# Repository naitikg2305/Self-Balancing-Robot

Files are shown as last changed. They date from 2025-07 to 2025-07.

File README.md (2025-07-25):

# Self-Balancing Robot

Welcome to the official project page for our Self-Balancing Robot. This website showcases the development, implementation, and final results of our autonomous two-wheeled balancing robot. Built as part of our control systems course (ENEE/ENME 461), this project merges hardware, software, and control theory into a compact, responsive platform.

---

## 🚀 Introduction

Inspired by the classic inverted pendulum problem, our robot demonstrates real-time balance using sensor feedback and PID control. It uses an ESP32 microcontroller, an MPU6050 IMU, and two DC gear motors controlled via a dual H-bridge. The challenge? Keep the robot upright on just two wheels—like a miniature Segway.

---

## 🛠️ Hardware Design

Our robot features:

- **Microcontroller:** ESP32 (DevKit v1)
- **Sensor:** MPU6050 (6-DOF IMU)
- **Motors:** 2x Pololu 3701 6V DC gear motors
- **Motor Driver:** L298N Dual H-Bridge
- **Power:** 12V Li-ion battery, 2x buck converters for 5V/3.3V
- **Frame:** 3D-printed chassis, with electronics mounted low for stability
- **Extras:** Darth Vader figurine on top for aesthetics!

> **Wiring Note:** We routed power from the 12V battery through buck converters to deliver clean 5V and 3.3V for logic and sensor components. All grounds from the Arduino, H-bridge, IMU, and buck converters are tied together to form a common ground reference. Motor power lines run directly from the battery to the L298N to handle current draw, while logic control pins are connected from the Arduino to the H-bridge via digital pins. I²C lines from the MPU6050 are connected to A4 and A5, with pull-up resistors handled internally. Each connection was tested using a multimeter for continuity, and critical joints were soldered and insulated with shrink wrap for durability.

All components were selected based on torque calculations and center of mass optimization. The wheels are 5 inches in diameter, offering a balance between responsiveness and ground clearance.

> The IMU is mounted close to the motors to reduce sensor lag and noise, while the battery is positioned low in the chassis to help with overall center of mass and balancing. The buck converters provide stable 5V and 3.3V rails from the main 12V battery, which also directly powers the motors and is safe for the Arduino’s VIN input (which tolerates up to 12V). Even with a 2V drop across the motors, our logic power is regulated and isolated from load variations.

### 🧵 Wiring Details

We routed power from the 12V battery through buck converters to deliver clean 5V and 3.3V for logic and sensor components. All grounds from the Arduino, H-bridge, IMU, and buck converters are tied together to form a common ground reference. Motor power lines run directly from the battery to the L298N to handle current draw, while logic control pins are connected from the Arduino to the H-bridge via digital pins. I²C lines from the MPU6050 are connected to A4 and A5, with pull-up resistors handled internally. Each connection was tested using a multimeter for continuity, and critical joints were soldered and insulated with shrink wrap for durability.

---

---

## 📐 CAD and Mechanical Assembly

The chassis was designed using Fusion360 and printed with PLA. The base houses the motors, driver, and battery. A custom bracket mounts the IMU at wheel axle level to reduce measurement noise. Zip ties and shrink tubing were used to secure and organize wires.

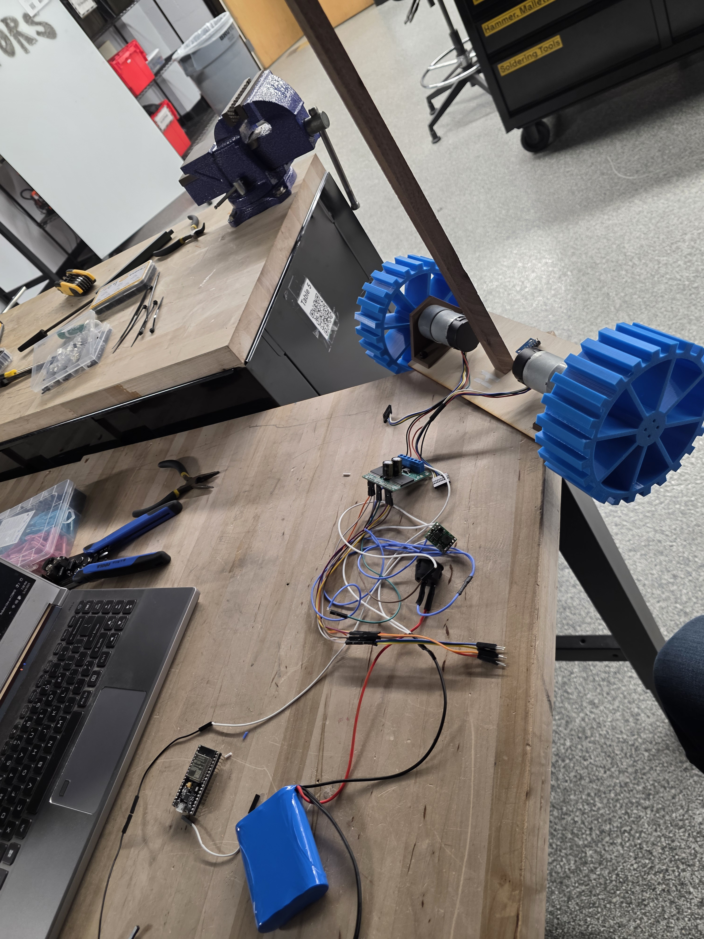
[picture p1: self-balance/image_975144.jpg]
 
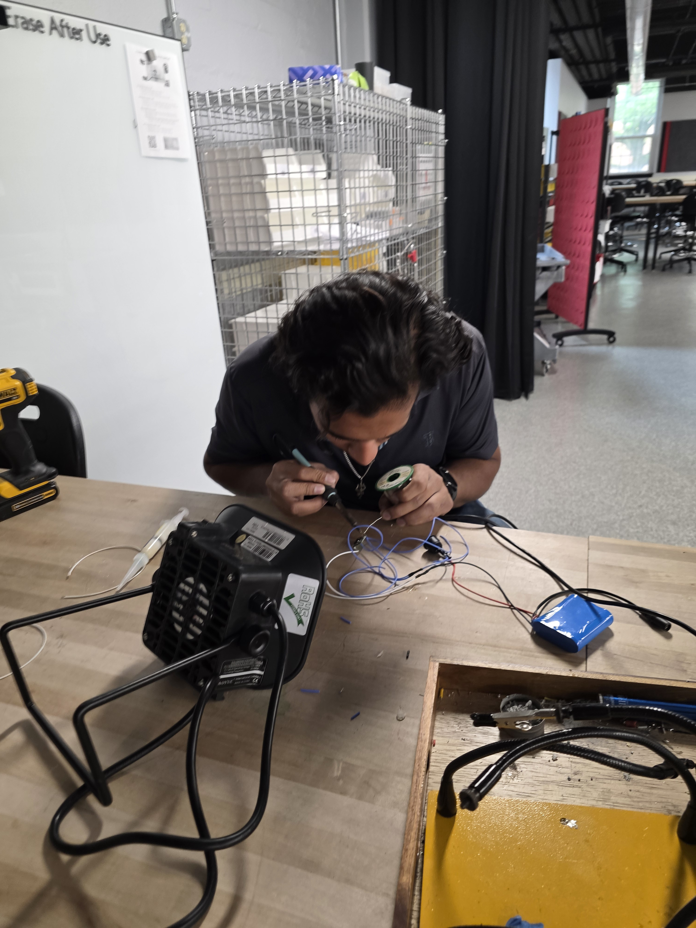
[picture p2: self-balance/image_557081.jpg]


---

## 🧠 Control System

We implemented a PD (Proportional-Derivative) control loop in C++ on the ESP32. Real-time pitch angle is read from the MPU6050, processed, and used to drive the motors with appropriate speed and direction. The system runs a loop every few milliseconds and includes a safety cutoff if the robot tilts beyond ±25°.

Key features:
- MPU6050 offset calibration at boot
- PWM-based motor control
- Dead zone for motor inputs below threshold
- Safety limits for excessive tilt

---

## 🧪 Testing and Tuning

Initial tuning was done using only the proportional term (Kp). We observed oscillations and instability at high Kp values. Adding the derivative term (Kd) improved stability and response time.

Final stable tuning:
- Kp: 3
- Kd: 300–450 (varies by configuration)

We used MS Excel’s Data Streamer to collect and visualize data from serial output, allowing analysis of angle, error, and motor input over time.

---

## 📹 Demo and Results

Our robot successfully balances under mild disturbances and showcases dynamic feedback in action. It reacts quickly, stabilizes after nudges, and remains upright unless excessive weight or tilt is applied.

---

## 🔧 Full Parts List

Refer to the shopping list document for exact components. Major items include:
- ESP32 DevKit
- MPU6050 IMU
- L298N Motor Driver
- 2x DC Gear Motors
- 12V Li-ion Battery
- 2x Buck Converters
- Custom 3D Printed Frame
- Darth Vader Figurine 😎
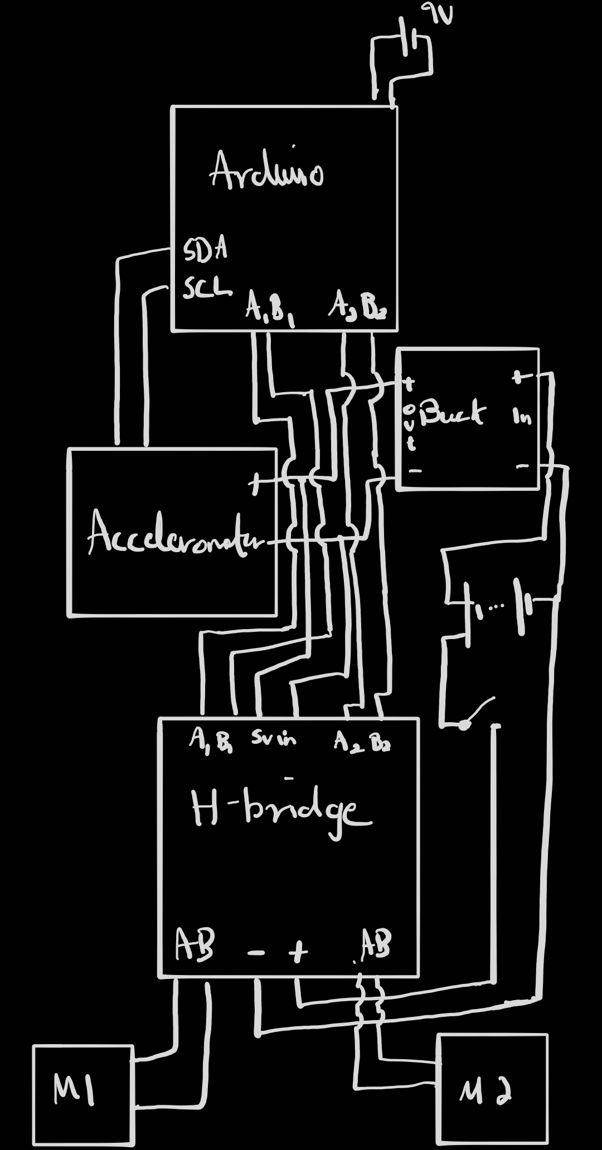
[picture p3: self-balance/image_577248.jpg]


---
## 🔌 Wiring Table

| Function | Component | Arduino Pin | Direction | Notes |
|---|---|---|---|---|
| Motor A DIR 1  | H-Bridge INA1 | D7 | Output | Sets forward/reverse |
| Motor A DIR 2  | H-Bridge INB1 | D8 | Output | |
| Motor A PWM | H-Bridge PWM1  | D5 | PWM Output | |
| Motor B DIR 1  | H-Bridge INA2 | D9 | Output | |
| Motor B DIR 2  | H-Bridge INB2 | D10 | Output | |
| Motor B PWM | H-Bridge PWM2  | D6 | PWM Output | |
| I²C SDA | MPU6050 | A4 | I²C | Connects to MPU6050 SDA |
| I²C SCL | MPU6050 | A5 | I²C | Connects to MPU6050 SCL |
| 5V Logic Power | H-Bridge / IMU  | - | Power | From 5V buck converter |
| GND | All Devices | - | Ground | Common ground for all |
| VIN | 9V Battery | VIN | Power Input | Powers Arduino Uno |

---

## 📅 Timeline

**Week 1:**
- Finalize CAD and ESP32 code
- Test IMU communication
- Set up buck converters

**Week 2:**
- Assemble robot frame
- Integrate electronics
- Start PID integration

**Week 3:**
- Tune PID controller
- Perform final testing
- Record demo and finalize documentation

---

## 🎓 Conclusion

This project was a successful application of control theory, hardware integration, and real-time feedback systems. Despite minor hardware limitations (motor torque, wheel grip), we achieved a reliable self-balancing robot that visually and functionally reflects our knowledge in embedded control.

---

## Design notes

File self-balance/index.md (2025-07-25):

---
title: "Self-balancing Robot using PID control"
date: "2025-05-20"
tags: ["PID Control", "IOT"]
summary: "This website showcases the development, implementation, and final results of our autonomous two-wheeled balancing robot."
youtube: "https://youtube.com/..."
featured: true   # only include if it's a featured project

stls: ["./wheel.stl"]
excels: ["./data/PD_kp3_kd0.25.csv","./data/PDkp3kd250.csv","./data/PDkp3kd650_final.csv"]
docs: ["./proposal.docx", "./report.docx","./shopping.docx"]
---

# Self-Balancing Robot

Welcome to the official project page for our Self-Balancing Robot. This website showcases the development, implementation, and final results of our autonomous two-wheeled balancing robot. Built as part of our control systems course (ENEE/ENME 461), this project merges hardware, software, and control theory into a compact, responsive platform.

---

## 🚀 Introduction

Inspired by the classic inverted pendulum problem, our robot demonstrates real-time balance using sensor feedback and PID control. It uses an ESP32 microcontroller, an MPU6050 IMU, and two DC gear motors controlled via a dual H-bridge. The challenge? Keep the robot upright on just two wheels—like a miniature Segway.

---

## 🛠️ Hardware Design

Our robot features:

- **Microcontroller:** ESP32 (DevKit v1)
- **Sensor:** MPU6050 (6-DOF IMU)
- **Motors:** 2x Pololu 3701 6V DC gear motors
- **Motor Driver:** L298N Dual H-Bridge
- **Power:** 12V Li-ion battery, 2x buck converters for 5V/3.3V
- **Frame:** 3D-printed chassis, with electronics mounted low for stability
- **Extras:** Darth Vader figurine on top for aesthetics!

> **Wiring Note:** We routed power from the 12V battery through buck converters to deliver clean 5V and 3.3V for logic and sensor components. All grounds from the Arduino, H-bridge, IMU, and buck converters are tied together to form a common ground reference. Motor power lines run directly from the battery to the L298N to handle current draw, while logic control pins are connected from the Arduino to the H-bridge via digital pins. I²C lines from the MPU6050 are connected to A4 and A5, with pull-up resistors handled internally. Each connection was tested using a multimeter for continuity, and critical joints were soldered and insulated with shrink wrap for durability.

All components were selected based on torque calculations and center of mass optimization. The wheels are 5 inches in diameter, offering a balance between responsiveness and ground clearance.

> The IMU is mounted close to the motors to reduce sensor lag and noise, while the battery is positioned low in the chassis to help with overall center of mass and balancing. The buck converters provide stable 5V and 3.3V rails from the main 12V battery, which also directly powers the motors and is safe for the Arduino’s VIN input (which tolerates up to 12V). Even with a 2V drop across the motors, our logic power is regulated and isolated from load variations.

### 🧵 Wiring Details

We routed power from the 12V battery through buck converters to deliver clean 5V and 3.3V for logic and sensor components. All grounds from the Arduino, H-bridge, IMU, and buck converters are tied together to form a common ground reference. Motor power lines run directly from the battery to the L298N to handle current draw, while logic control pins are connected from the Arduino to the H-bridge via digital pins. I²C lines from the MPU6050 are connected to A4 and A5, with pull-up resistors handled internally. Each connection was tested using a multimeter for continuity, and critical joints were soldered and insulated with shrink wrap for durability.

---

---

## 📐 CAD and Mechanical Assembly

The chassis was designed using Fusion360 and printed with PLA. The base houses the motors, driver, and battery. A custom bracket mounts the IMU at wheel axle level to reduce measurement noise. Zip ties and shrink tubing were used to secure and organize wires.

 


---

## 🧠 Control System

We implemented a PD (Proportional-Derivative) control loop in C++ on the ESP32. Real-time pitch angle is read from the MPU6050, processed, and used to drive the motors with appropriate speed and direction. The system runs a loop every few milliseconds and includes a safety cutoff if the robot tilts beyond ±25°.

Key features:
- MPU6050 offset calibration at boot
- PWM-based motor control
- Dead zone for motor inputs below threshold
- Safety limits for excessive tilt

---

## 🧪 Testing and Tuning

Initial tuning was done using only the proportional term (Kp). We observed oscillations and instability at high Kp values. Adding the derivative term (Kd) improved stability and response time.

Final stable tuning:
- Kp: 3
- Kd: 300–450 (varies by configuration)

We used MS Excel’s Data Streamer to collect and visualize data from serial output, allowing analysis of angle, error, and motor input over time.

---

## 📹 Demo and Results

Our robot successfully balances under mild disturbances and showcases dynamic feedback in action. It reacts quickly, stabilizes after nudges, and remains upright unless excessive weight or tilt is applied.

---

## 🔧 Full Parts List

Refer to the shopping list document for exact components. Major items include:
- ESP32 DevKit
- MPU6050 IMU
- L298N Motor Driver
- 2x DC Gear Motors
- 12V Li-ion Battery
- 2x Buck Converters
- Custom 3D Printed Frame
- Darth Vader Figurine 😎


---
## 🔌 Wiring Table

| Function | Component | Arduino Pin | Direction | Notes |
|---|---|---|---|---|
| Motor A DIR 1  | H-Bridge INA1 | D7 | Output | Sets forward/reverse |
| Motor A DIR 2  | H-Bridge INB1 | D8 | Output | |
| Motor A PWM | H-Bridge PWM1  | D5 | PWM Output | |
| Motor B DIR 1  | H-Bridge INA2 | D9 | Output | |
| Motor B DIR 2  | H-Bridge INB2 | D10 | Output | |
| Motor B PWM | H-Bridge PWM2  | D6 | PWM Output | |
| I²C SDA | MPU6050 | A4 | I²C | Connects to MPU6050 SDA |
| I²C SCL | MPU6050 | A5 | I²C | Connects to MPU6050 SCL |
| 5V Logic Power | H-Bridge / IMU  | - | Power | From 5V buck converter |
| GND | All Devices | - | Ground | Common ground for all |
| VIN | 9V Battery | VIN | Power Input | Powers Arduino Uno |

---

## 📅 Timeline

**Week 1:**
- Finalize CAD and ESP32 code
- Test IMU communication
- Set up buck converters

**Week 2:**
- Assemble robot frame
- Integrate electronics
- Start PID integration

**Week 3:**
- Tune PID controller
- Perform final testing
- Record demo and finalize documentation

---

## 🎓 Conclusion

This project was a successful application of control theory, hardware integration, and real-time feedback systems. Despite minor hardware limitations (motor torque, wheel grip), we achieved a reliable self-balancing robot that visually and functionally reflects our knowledge in embedded control.

---

## 📁 Appendix

- [Final Report (PDF)](link-to-pdf)
- [Shopping List (PDF)](link-to-shopping-list)
- [Proposal and Technical Details](link-to-proposal)
- [Demo Videos](https://drive.google.com/drive/folders/1PLejTndw4LxtoSVA8v18seIj9uFeChZ4?usp=sharing)

---

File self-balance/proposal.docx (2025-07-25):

# Name: Naitik Gupta, Stephen Snyder

# Self-Balancing Robot Project Proposal

# Project Description and Justification

We are designing a self-balancing two-wheeled robot using an ESP32 microcontroller, an MPU6050 IMU, two 6V DC gear motors (Pololu 3701), and a dual H-bridge motor driver (L298N). The robot will maintain balance using PID control, with real-time feedback from the IMU mounted near the wheel axle to sense pitch angle and angular velocity. All control logic and sensor processing will be executed on the ESP32, powered through a buck converter. A second buck converter powers the motor driver logic separately.

The robot is powered by a 12V Li-ion battery pack, chosen to provide sufficient headroom for torque delivery. The L298N introduces a voltage drop of approximately 2V, meaning motors effectively receive ~10V. At this voltage, the selected gear motors can deliver up to 2.0 kg·cm stall torque. Our torque calculations indicate that to correct a forward tip of 5 degrees with our estimated 1 kg robot (0.6 kg electronics below axle, 0.2 kg figurine above axle), approximately 0.024 Nm (2.45 kg·cm) of total torque is required. With two motors, each motor needs to provide around 1.2 kg·cm of torque, which is well within the motors’ performance range when overdriven safely at 10V. The use of 5-inch wheels ensures good ground contact and stability, while the low placement of the battery and electronics counterbalances the raised decorative figurine.

At its core, this project aims to explore the challenge and elegance of balancing a robot on just two wheels — a feat that captures the essence of modern control systems. Achieving upright stability using only sensor feedback and dynamic motor control illustrates how theory translates into practical, physical behavior. It's an exciting demonstration of how real-time physics, electronics, and programming converge into a functioning, responsive system.

This project is worthwhile as it combines essential control systems concepts such as feedback, PID tuning, real-time actuation, and dynamic stabilization. It gives us hands-on experience with nonlinear system control, sensor fusion, and system modeling—key competencies in control engineering.

# Feasibility and Planning

We have studied self-balancing robot implementations and PID control techniques using MPU6050 and ESP32 platforms. We are implementing complementary filtering or Kalman filtering to obtain a stable pitch estimate. Motor speed and direction will be controlled via PWM signals generated by the ESP32 and routed through the L298N. All hardware components have been selected to match our physical requirements and torque targets. We understand the limitations of the L298N and have compensated by using a 12V battery with dedicated buck converters to provide stable 5V and 3.3V outputs for the ESP32 and driver logic respectively.

# Timeline and Milestones

- 📆 Week 1 (Apr 21 – Apr 27): Finalize software structure, write low-level drivers for ESP32, and implement IMU communication and filtering. Finalize CAD design for robot chassis and mounts. Test buck converters and individual hardware modules.
- 📆 Week 2 (Apr 28 – May 4): Assemble mechanical frame and install all electronic components. Test full power distribution and PWM-based motor control. Begin integrating IMU data into balance logic.
- 📆 Week 3 (May 5 – May 11): Tune PID controller and verify balance behavior. Perform rigorous testing with weight distribution and evaluate robustness. Finalize report, demonstration, and documentation.

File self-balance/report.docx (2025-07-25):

ENME/ENEE 461

Controls Project - Self-Stabilizing Robot

Stephen Snyder, Naitik Gupta

Introduction

Goal

Our main goal for this project is to apply our knowledge and learnings from this semester into a real world application that presents our mastery of the course. For this, we chose to design a self-balancing robot, similar in design to a Segway. We got our inspiration from the inverted pendulum project where we had to design a PD controller that kept a metal pendulum upright using a metal arm that spins. In our case, we used two 12v motors that were fast and had enough torque to keep the robot from tipping over too much.

Hypothesis

Using a PD controller with an accelerometer that calculates the change in angle as input is a viable way to control two motors with varying speeds to keep a self-balancing robot upright.

Design

CAD Model

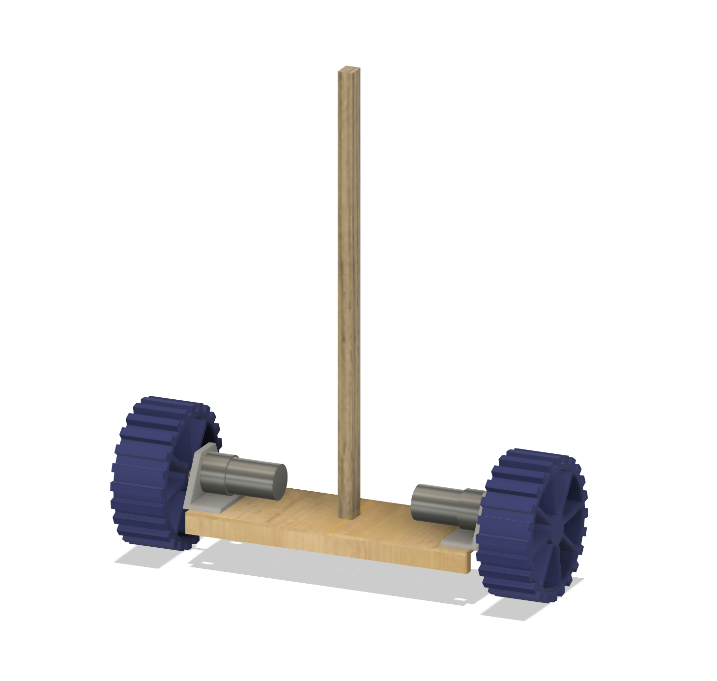
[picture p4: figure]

Fig 1: CAD model of the robot

Our robot was designed in Fusion360. It consists of two motors mounted to a baseplate, wheels on the ends, and a stick in the middle. During the fabrication process, extra support pieces were added to the underside of the base to keep it from bowing, which has been reflected in the CAD model.

Motor Justification

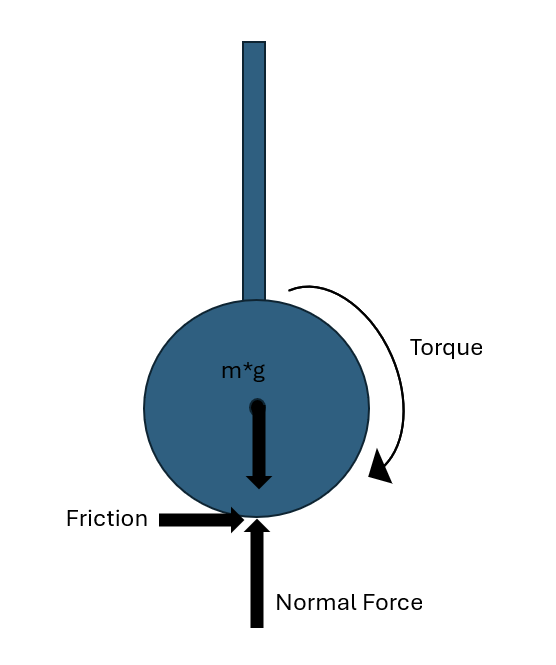
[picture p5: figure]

Fig 2: Free-body diagram of the robot

We derived the necessary torque per motor using a rough force balance of the vehicle and the motor torque, assuming a friction coefficient of ~0.3, a wheel radius of 130mm, and a weight of 1kg.

T =m*g*c_f *r*1/2

This worked out to be 0.191 N-m (1.95 kg-cm) of torque per motor in order to make our robot move.

Parts Used

We used two 12V DFRobot motors. They had a max speed of 251RPM and a stall torque of 18 kg-cm, which was enough for the motors to be able to spin even when the voltage applied was well under 12V.

Two motor mounting brackets designed by us were printed in PLA to connect the motors to the baseplate.

A Pololu MD03A Dual H-Bridge was use to control the power sent to the motors. An H-bridge allows us to control both the direction of the motors and the speed, which is necessary for our controller to function.

A 12V, 3000mAh rechargeable Li-ion battery was used as our power supply for the motors. This had the voltage and the current discharge rate necessary to power our motors, while also being lightweight. A kill switch was soldered into the power output wire to allow us to quickly shut down the robot.

A buck converter was used to step down the voltage from 12V to 5V to provide power to the accelerometer and H-bridge.

We intended to use an ESP32 as our microcontroller due to its 240MHz response speed which would provide enough speed to react to changing angle values. However, the ESP32 gave us a lot of problems. Specific drivers needed to be found for it to even interact with our computer(silicon labs cp210x USB to UART drivers). Then, the boot button needed to be held every time we tried to upload code. The COM port kept switching every time we tried to upload the code, as did the board drivers in arduino: we used ALKS 4D sometimes, 4d Systems drivers other times. Finally, once the code was able to be uploaded, the GPIO pins outputted negative voltage signals and could not switch H-bridge logic, so we decided not to use it.

We instead used an Arduino Uno, and even with a slower speed of 16MHz it was fast enough to effectively control the robot.

An Adafruit MPU6050 6-DOF accelerometer was used to get angle readings. It was mounted low to limit noise, as close to the axles of the motor around which the robot would primarily turn, and readings from only the X-direction were used.

Our wheels were 130mm in diameter and were printed in TPU to give it better grip. We wanted the wheels to be large to accommodate our circuits and battery without throwing the rover too off balance. 130mm enabled us to fit the battery at the bottom and the rest of the circuits over the axle which gave us just enough slight imbalance for our PID to work and self balance. We later wrapped the wheels in duct tape to give it even more grip.

A small PLA wheel hub with a set screw was used to connect the motor shaft to the wheels.

A piece of 1/8" (3.175mm) plywood was laser cut to 100x275mm as the baseplate.

A scrap piece of wood, roughly 14x18x420mm, was placed vertically in the center both to give a clear indicator of the current angle and to add enough weight above the robot to unbalance it.

Two pieces of scrap wood, roughly 8x17x275mm, were used to support the baseplate from bowing.

With the exception of the battery, which was mounted to the underside to keep it more secure, all parts were mounted on the baseplate. As much of the weight as possible was placed above the axis of rotation to cause the robot to be unstable while at rest.

Wiring diagram

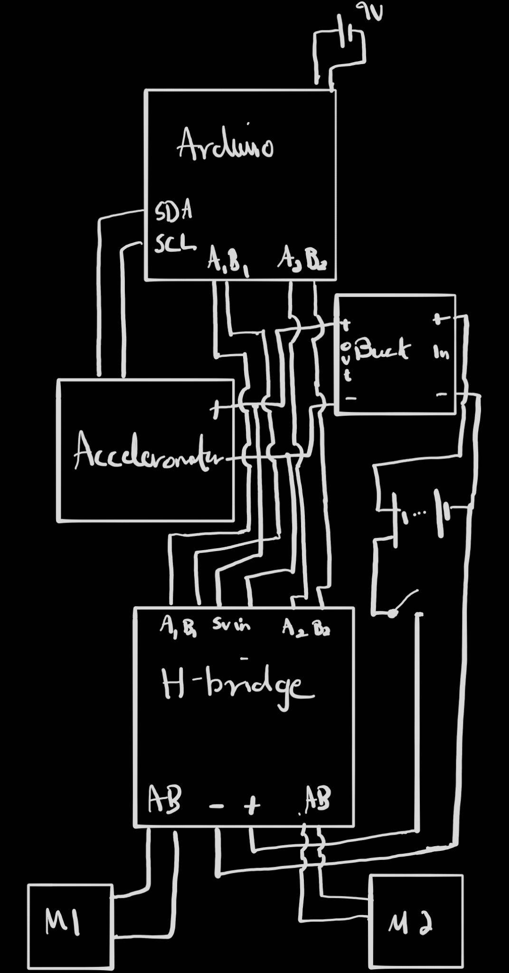
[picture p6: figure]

Fig 3: Wiring diagram

Pinout

Function | Component | Arduino Pin | Direction | Notes
Motor A DIR 1 | H-Bridge INA1 | 7 | Output | Sets forward/reverse
Motor A DIR 2 | H-Bridge INB1 | 8 | Output | Sets forward/reverse
Motor A PWM | H-Bridge PWM1 | 5 | PWM Output | Sets speed
Motor B DIR 1 | H-Bridge INA2 | 9 | Output | Sets forward/reverse
Motor B DIR 2 | H-Bridge INB2 | 10 | Output | Sets forward/reverse
Motor B PWM | H-Bridge PWM2 | 6 | PWM Output | Sets speed
I²C SDA | MPU6050 | A4 | I²C | Connects to MPU6050 SDA
I²C SCL | MPU6050 | A5 | I²C | Connects to MPU6050 SCL
5V Logic Power | H-Bridge / MPU6050 | - | Power | From 5V buck converter
GND | All Devices | - | Ground | Common ground for all
VIN (Arduino) | 9V Battery | VIN | Power Input | Powers Arduino Uno
Function | Component | Arduino Pin | Direction | Notes

Final Design

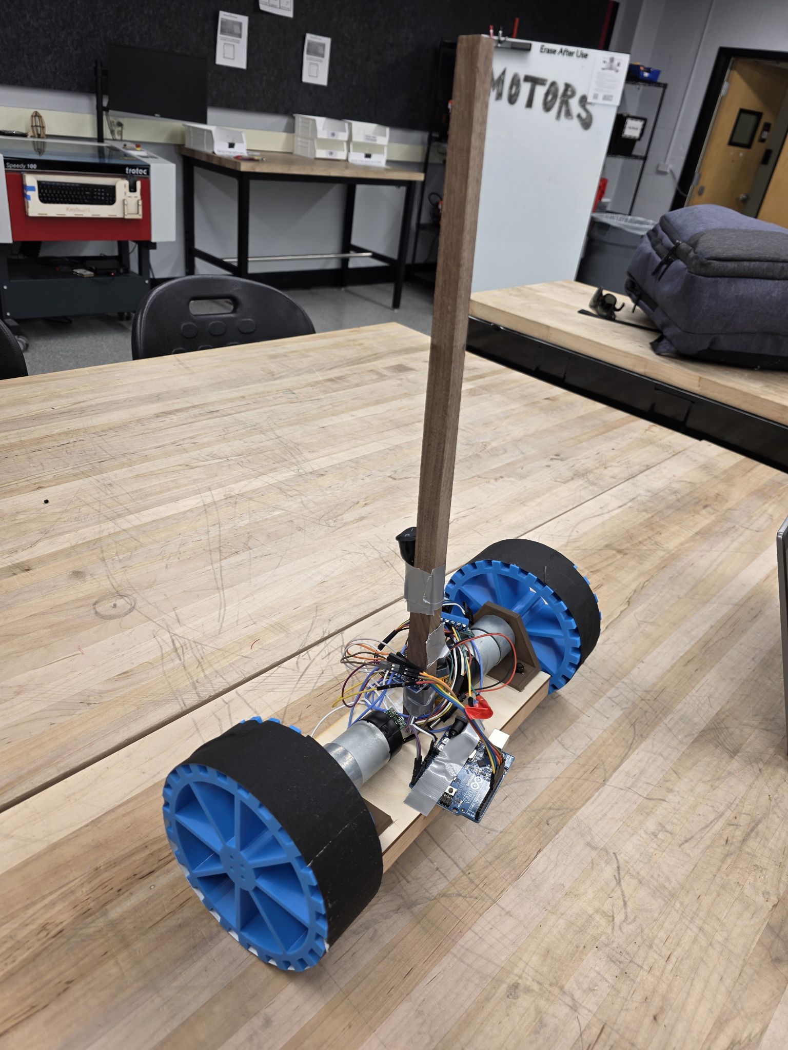
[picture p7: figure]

Fig 4: Fully built robot

Code

Initial Calibration Code

We first tested the output from the accelerometer using the code below, found as an example within the accelerometer library. This outputs the angle in the X direction, the acceleration in the Y direction, and the gyroscopic force in the Z direction. The angle value was the least noisy of the three, and the X direction allowed for simple mounting to the stick, so we used that value for the remainder of the code. This code also uses the mpu.calcOffsets() function, which ensures that all values are referenced from the starting position of the accelerometer. This means we had to hold the robot in the vertical position when starting the code, in order to properly reference the zero angle point to vertical.

#include <Wire.h>

#include <MPU6050_light.h>

MPU6050 mpu(Wire);

void setup() {

Serial.begin(9600);

delay(1000);

Wire.begin(); // On Uno: SDA = A4, SCL = A5

byte status = mpu.begin();

Serial.print("MPU6050 status: ");

Serial.println(status);

while (status != 0) {

delay(1000);

Serial.println("MPU not connected...");

}

Serial.println("Calibrating gyro...");

delay(1000);

mpu.calcOffsets(); // gyro and accel calibration

Serial.println("Done!");

}

void loop() {

mpu.update();

// Angle in X-axis (pitch) for balancing

Serial.print("Angle X (Pitch): ");

Serial.print(mpu.getAngleX());

Serial.print("\t");

// Raw acceleration and gyro

Serial.print("Accel Z: ");

Serial.print(mpu.getAccZ());

Serial.print("\tGyro Y: ");

Serial.println(mpu.getGyroY());

delay(100);

}

We then tested the motors using basic H-bridge code, using the INA and INB pins to switch the direction of current flowing through our motors, and the PWM pins to determine the voltage applied to them. This helped us determine the pin order to use to get the motors to spin in the correct direction. We also tested for the lower bound for speed. With an input to the analogWrite() function of approximately 15, the motors would start to stall and would spin inconsistently. In order to keep our motors safe, the final code included a few lines that would stop the motors when the input dropped below 15.

#define INA1 8 // Direction 1

#define INB1 9 // Direction 2

#define PWM1 10 // Speed PWM

// Motor 2 (Right or B)

#define INA2 13 // Direction 1

#define INB2 12 // Direction 2

#define PWM2 11

void setup() {

Serial.begin(115200);

Serial.println("Starting Motor Test...");

pinMode(INA1, OUTPUT);

pinMode(INB1, OUTPUT);

pinMode(PWM1, OUTPUT);

pinMode(INA2, OUTPUT);

pinMode(INB2, OUTPUT);

pinMode(PWM2, OUTPUT);

}

void loop() {

Serial.println("Forward");

digitalWrite(INA1, HIGH);

digitalWrite(INB1, LOW);

analogWrite(PWM1, 16);

digitalWrite(INA2, LOW);

digitalWrite(INB2, HIGH);

analogWrite(PWM2, 16);

delay(2000);

Serial.println("Reverse");

digitalWrite(INA1, LOW);

digitalWrite(INB1, HIGH);

analogWrite(PWM1, 17);

digitalWrite(INA2, HIGH);

digitalWrite(INB2, LOW);

analogWrite(PWM2, 17);

delay(2000);

Serial.println("Brake");

digitalWrite(INA1, HIGH);

digitalWrite(INB1, HIGH);

analogWrite(PWM1, 0);

digitalWrite(INA2, HIGH);

digitalWrite(INB2, HIGH);

analogWrite(PWM2, 0);

delay(2000);

Serial.println("Coast");

digitalWrite(INA1, LOW);

digitalWrite(INB1, LOW);

analogWrite(PWM1, 0);

digitalWrite(INA2, LOW);

digitalWrite(INB2, LOW);

analogWrite(PWM2, 0);

delay(2000);

}

We then wrote the final PD controller code. We calculated the error during each step by subtracting the current angle from the target angle of 0 degrees. The proportional component could then be determined by multiplying our Kp value by that error. The derivative component was determined by first finding the time change between the current step and the previous step, and dividing that into the change in the error value between the current and previous step. This was then multiplied by the Kd value. The total motor input was found by adding these two components together, and this was sent to the PWM pins to determine speed.

We also included a safety stop into the program. The main code loop was placed within an eternal while loop, and we added a check at the end of each step to ask if the current angle had exceeded our safe limit of 25 degrees. If it had exceeded that limit, the code would break out of the main loop and stop everything.

#include <Wire.h>

#include <MPU6050_light.h>

MPU6050 mpu(Wire);

float prev = 0;

float target = 0;

float kP = 3;

float kD = 450 ;

unsigned long t;

float lowBound = 15;

#define L1 8

#define L2 9

#define R1 12

#define R2 13

#define LS 10

#define RS 11

void setup() {

Serial.begin(9600);

//pinmodes

pinMode(L1, OUTPUT);

pinMode(L2, OUTPUT);

pinMode(R1, OUTPUT);

pinMode(R2, OUTPUT);

pinMode(LS, OUTPUT);

pinMode(RS, OUTPUT);

Wire.begin(); // On Uno: SDA = A4, SCL = A5

byte status = mpu.begin();

Serial.print("MPU6050 status: ");

Serial.println(status);

while (status != 0) {

delay(1000);

Serial.println("MPU not connected...");

}

Serial.println("Calibrating gyro...");

delay(1000);

mpu.calcOffsets(); // gyro and accel calibration

Serial.println("Done!");

}

void loop() {

//mpu.update();

while(true){

mpu.update();

float current = float(mpu.getAngleX()); //read mpu

int timestep = millis()-t;

t = millis();

//error

float error = target-current;

//P

float P = error * kP;

//D

float D = kD * (error-prev)/timestep;

//overall

float motorInput = P + D ;//later

Serial.print(t);

Serial.print(",");

Serial.print (error);

Serial.print(",");

Serial.print (current) ;

Serial.print(",");

Serial.print (P) ;

Serial.print(",");

Serial.print (D) ;

Serial.print(",");

Serial.println (motorInput );

if(motorInput >= lowBound){

motorInput = constrain(motorInput,lowBound,255);

motorMove(motorInput,false);

}else if (motorInput <= -lowBound){

motorInput = constrain(motorInput,-255,-lowBound);

motorMove(abs(motorInput),true);

}else{

motorInput = 0;

motorStop();

}

prev = error; //for next cycle

if (abs(current) >= 25){

break;

}

}

motorStop();

while(true){}

}

void motorMove(int input, bool dir){

if(dir){ //forward

digitalWrite(L1, HIGH);

digitalWrite(L2, LOW);

digitalWrite(R1, HIGH);

digitalWrite(R2, LOW);

}else{

digitalWrite(L1, LOW);

digitalWrite(L2, HIGH);

digitalWrite(R1, LOW);

digitalWrite(R2, HIGH);

}

analogWrite(LS, input);

analogWrite(RS, input);

}

void motorStop(){

digitalWrite(L1, LOW);

digitalWrite(L2, LOW);

digitalWrite(R1, LOW);

digitalWrite(R2, LOW);

}

Results

Data Acquisition

We gathered data by using the MS Data Streamer add-on for Excel, which reads the serial port similarly to the Arduino Serial Monitor, and can record the printed data into a .csv file. We recorded values for the time, angle error, current angle, the proportional and derivative components, and the total motor input. The motor input and PD terms were the values inputted into the analogWrite() command, with 255 as the maximum mapping to a 12V motor input.

Initial guesses for Kp and Kd were tested by running the robot without power going to the motors, allowing us to read the values the Arduino was printing while we manually turned the robot. This let us ensure that those values made sense and would result in safe operation once power was turned on.

Proportional Controller

We began by testing with just the proportional controller by simply removing the line of code that added the P and D components together, and just using the P component as the motor input.

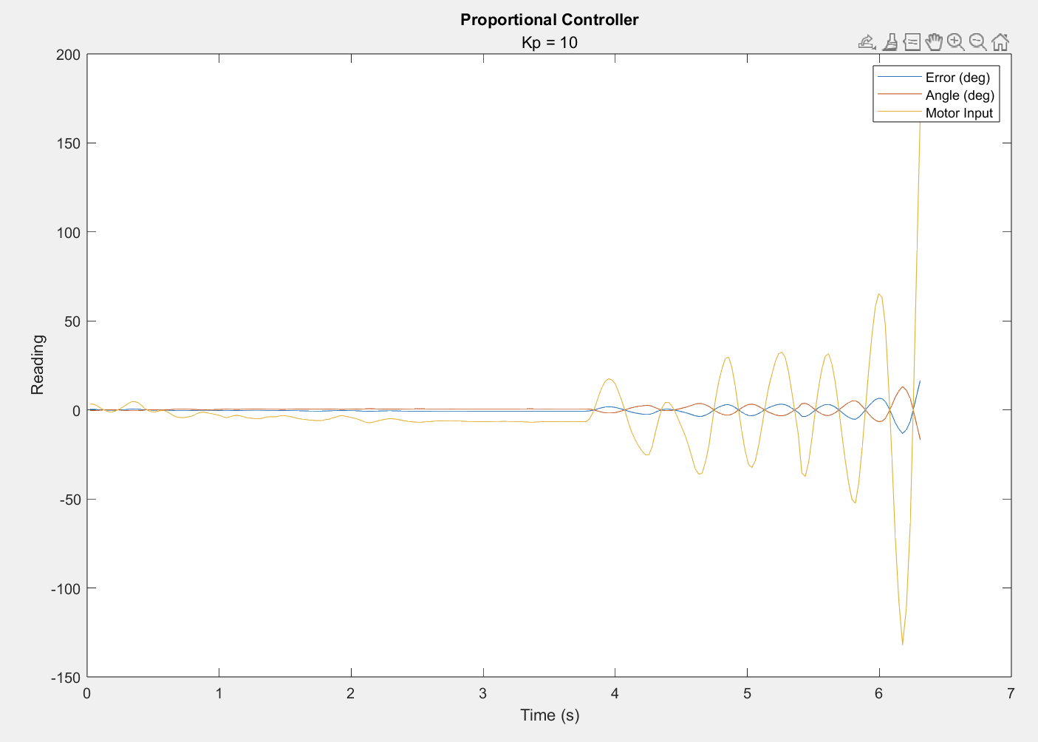
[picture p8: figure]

Fig 5: Proportional controller with Kp = 10

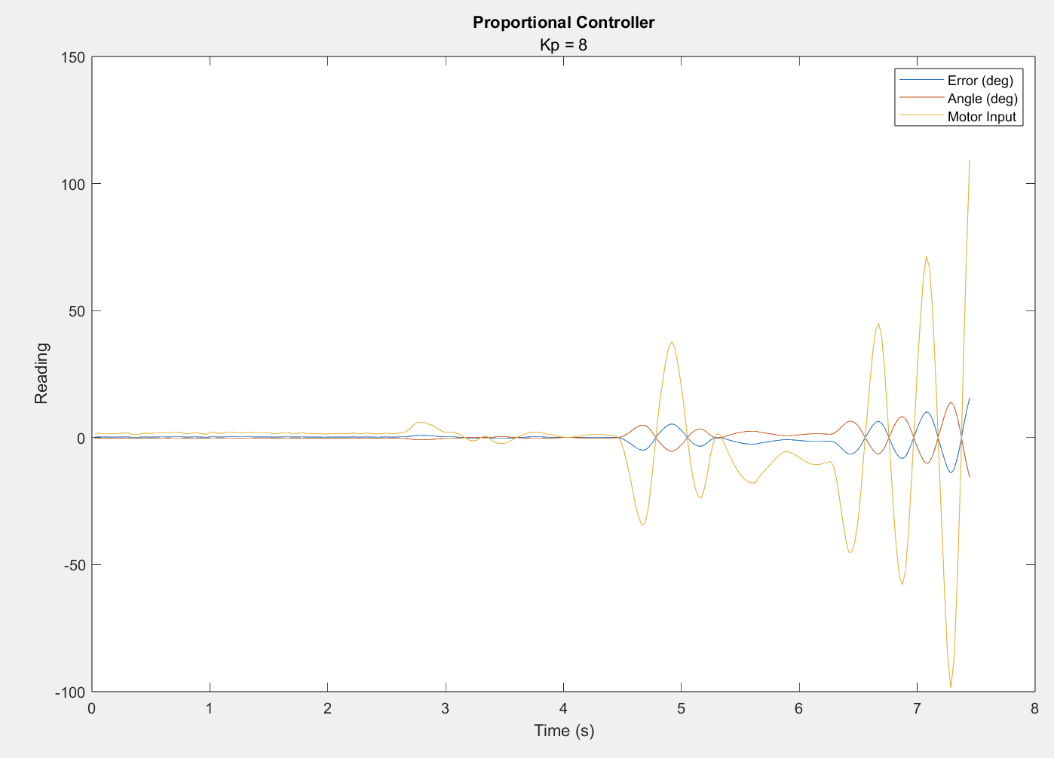
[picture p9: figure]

Fig 6: Proportional controller with Kp = 8

With higher values for Kp, the robot was unstable and experienced growing oscillations that resulted in it exceeding the safe angle limit we set.

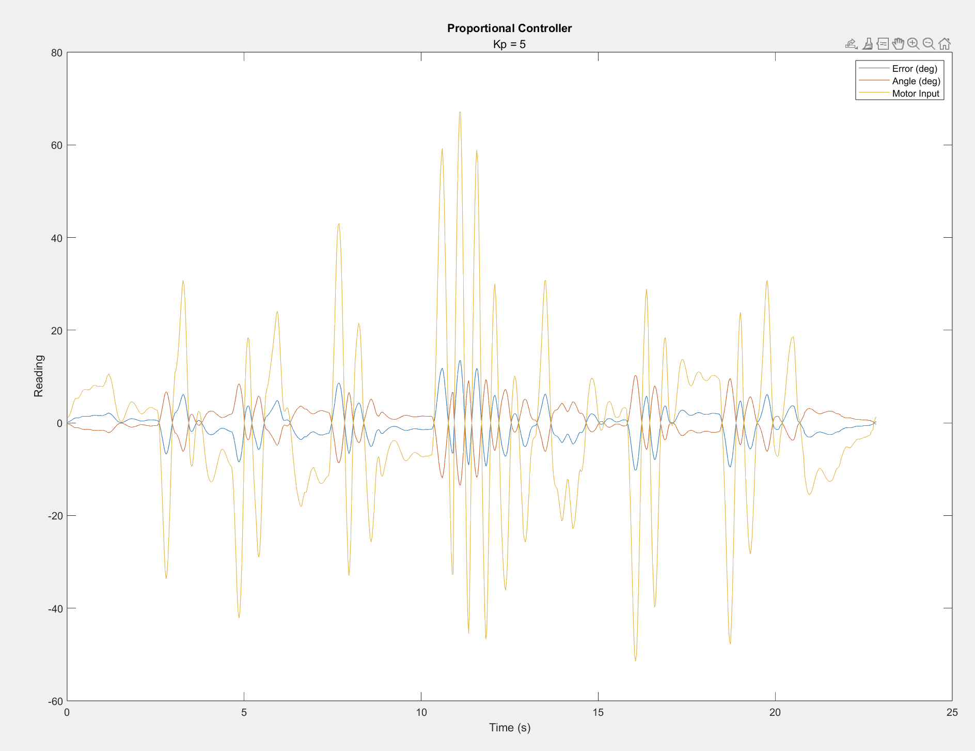
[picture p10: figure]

Fig 7: Proportional controller with Kp = 5

With a Kp of 5, the robot was stable to small disturbances. Larger disturbances caused it to oscillate a lot, as seen at about 10s in Fig #, but it eventually settled back down again.

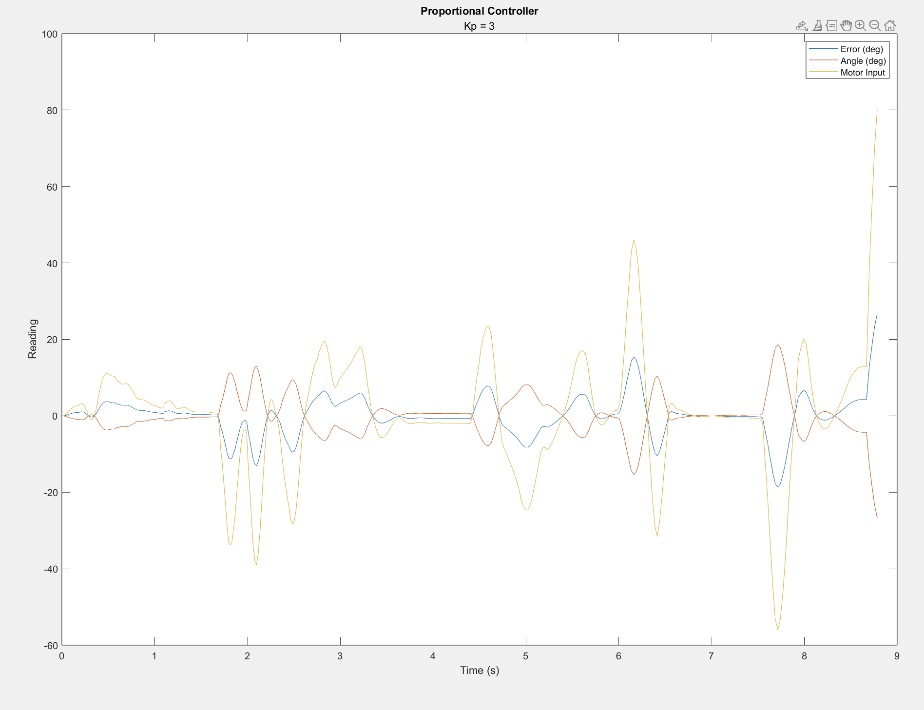
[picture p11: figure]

Fig 8: Proportional controller with Kp = 3

With a Kp value of 3, the oscillations were gone and the controller was stable. The settling time is dependent on the magnitude of the disturbance, but was around 2 seconds.

Proportional-Derivative Controller

To try and speed up the response, we added in the derivative term to make a PD controller.

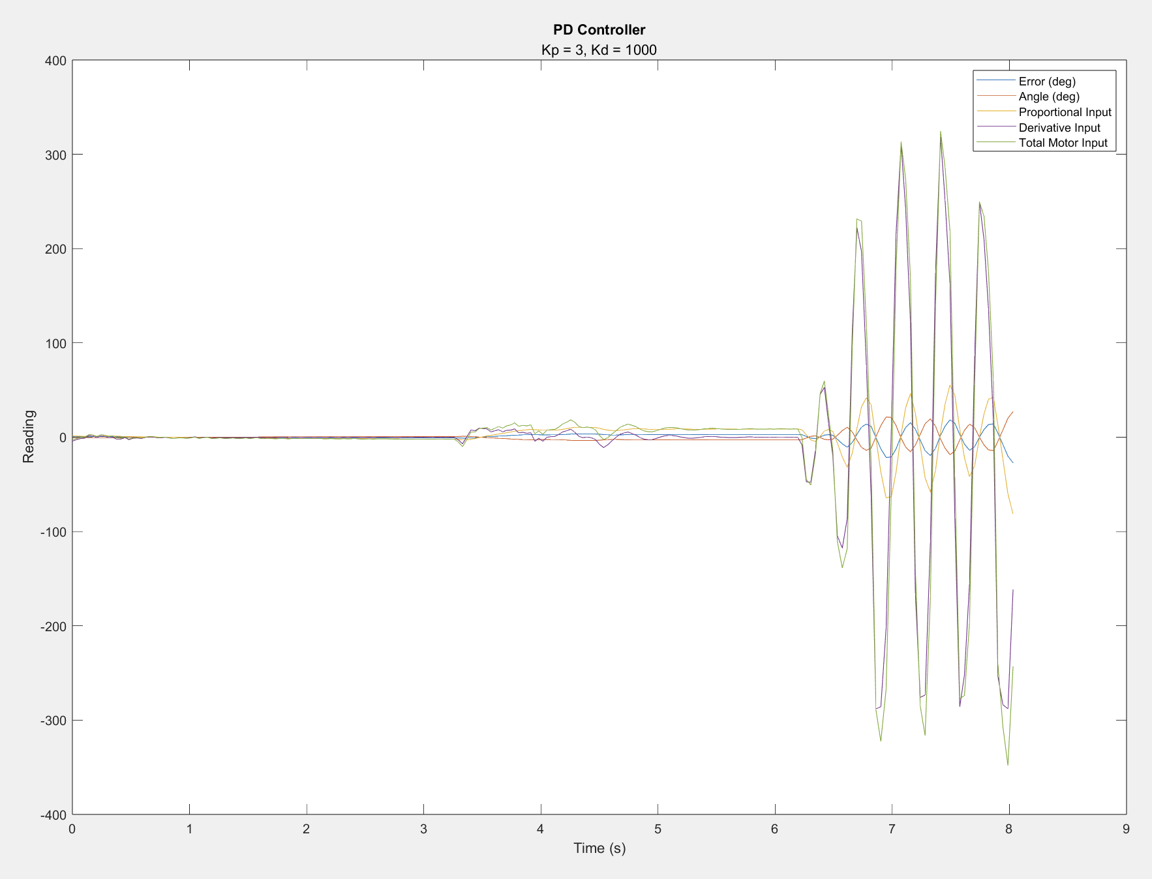
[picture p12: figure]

Fig 9: PD Controller with Kp = 3, Kd = 1000

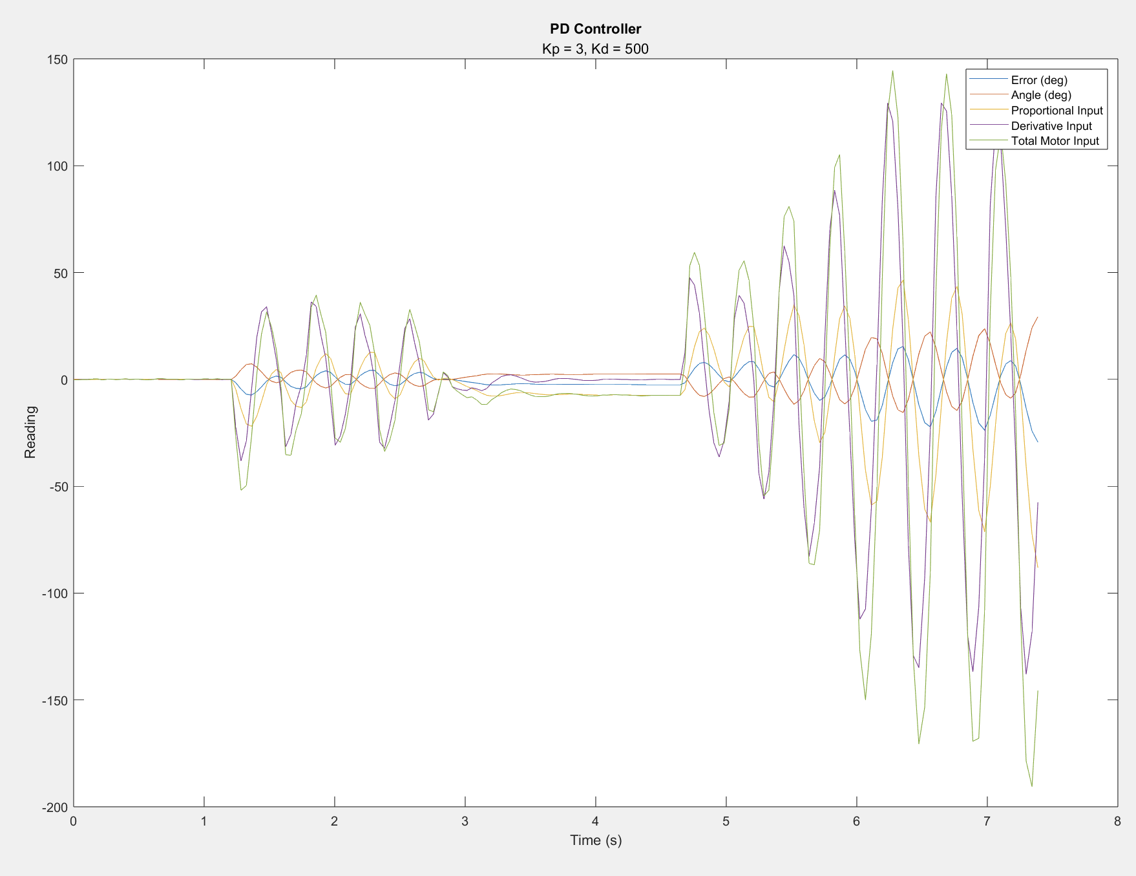
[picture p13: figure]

Fig 10: PD Controller with Kp = 3, Kd = 500

Similar to the proportional controller, higher values of Kd cause the robot to destabilize when disturbances are applied.

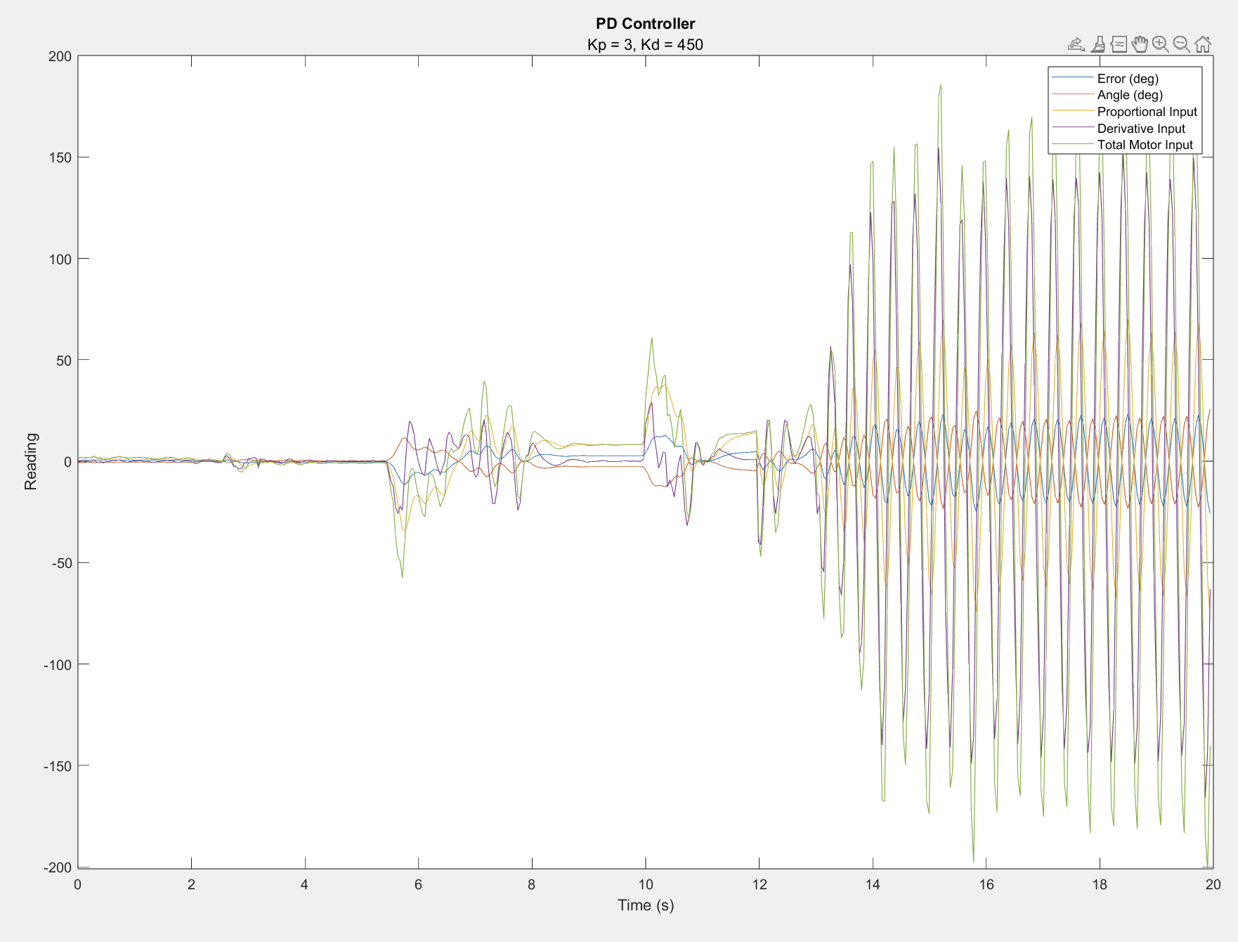
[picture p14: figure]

Fig 11: PD Controller with Kp = 3, Kd = 450

A Kd value of 4.5 caused the robot to be stable for very small disturbances, but is only marginally stable for larger disturbances, which caused it to oscillate continuously without decaying or stabilizing.

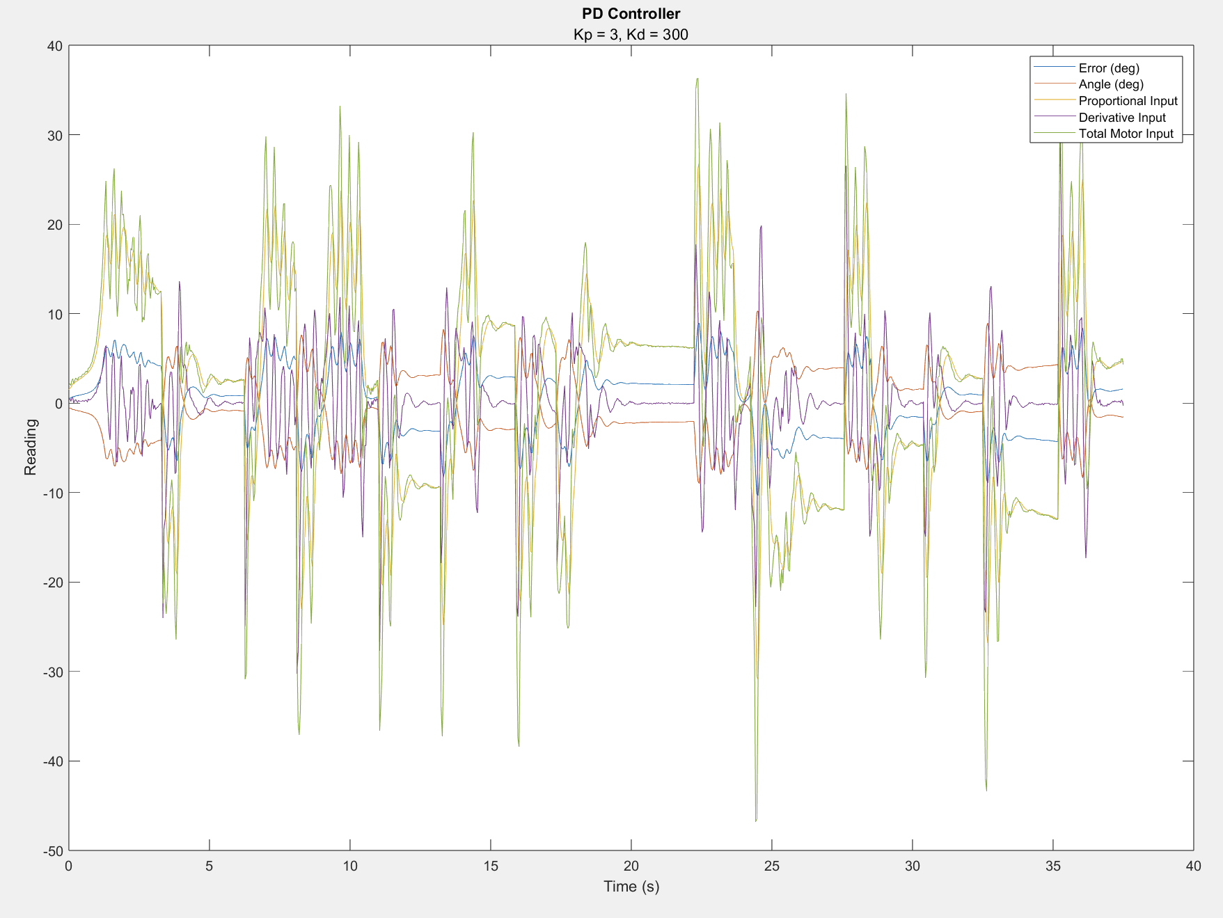
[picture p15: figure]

Fig 12: PD Controller with Kp = 3, Kd = 300

A Kd value of 3 kept the robot stable, and responded to disturbances slightly faster than the proportional controller, with a settling time of around 1.5 seconds. It also helped it travel less distance while stabilizing, which can be seen in some of the videos linked in the appendix.

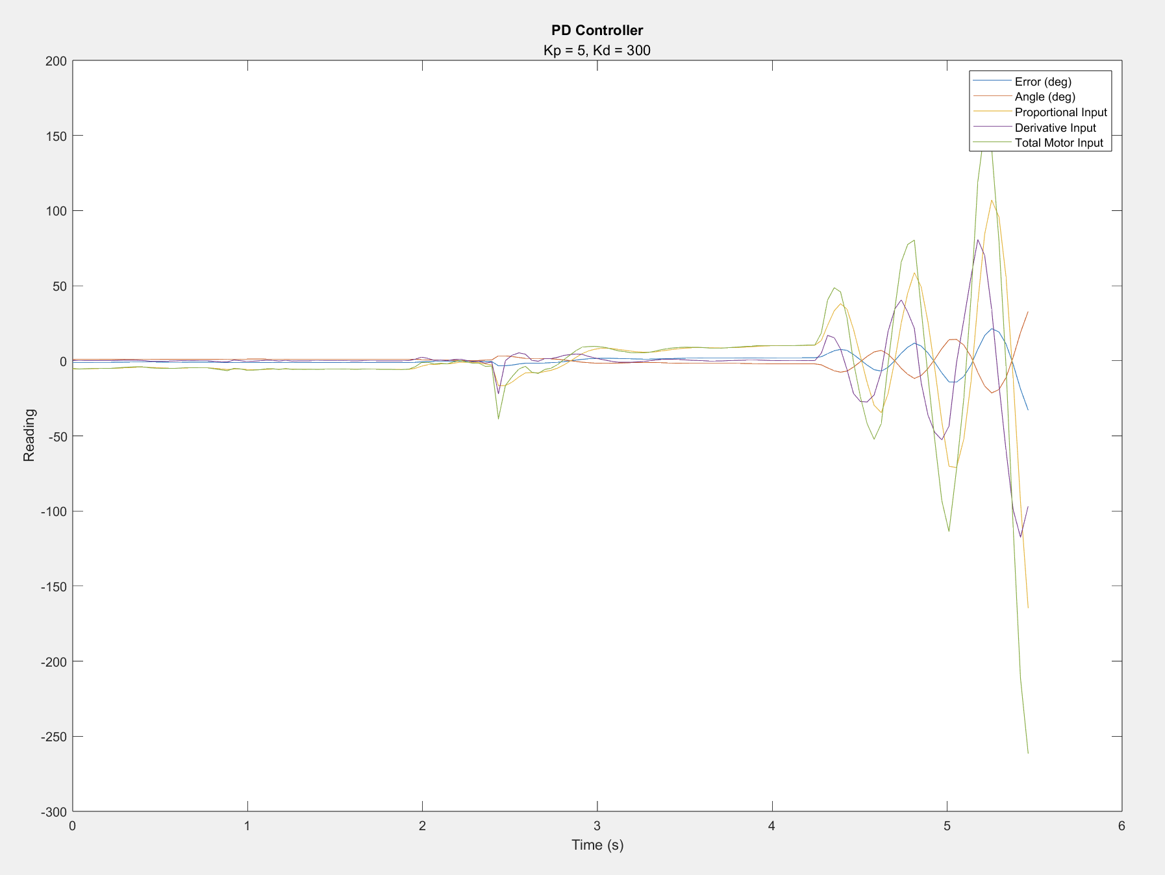
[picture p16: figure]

Fig 13: PD Controller with Kp = 5, Kd = 300

We also tested to see if the derivative term would help stabilize the controller for higher values of Kp, but the robot was still unstable.

Adding Extra Weight

Once the robot successfully balanced itself, we tested with an extra weight of approximately 0.3kg on the top of the stick. We were unable to find a combination of Kp and Kd such that the robot was able to rebalance itself back to vertical, but it also did not fall over completely. Instead, it would move in the direction the stick was pushed, acting similarly to a Segway. We believe this occurred because the robot could not achieve the speed or torque needed to push the added weight back up, but it did have the strength to keep it at an angle while it was in motion.

Conclusion

The robot was successful, though some improvements could have been made. The motors we used were too fast, and did not have enough torque at low speeds to move the robot. This caused some issues where the controller could not get the robot back to the correct angle because the motors could not move. The wheels we had also did not have enough grip, so at high speeds they would slip and the controller would not work properly. However, despite these issues, we found tuning values that worked and the PD controller successfully kept the robot stabilized against disturbances.

Appendix

A folder of assorted videos of our robot in action can be found here:

https://drive.google.com/drive/folders/1PLejTndw4LxtoSVA8v18seIj9uFeChZ4?usp=sharing

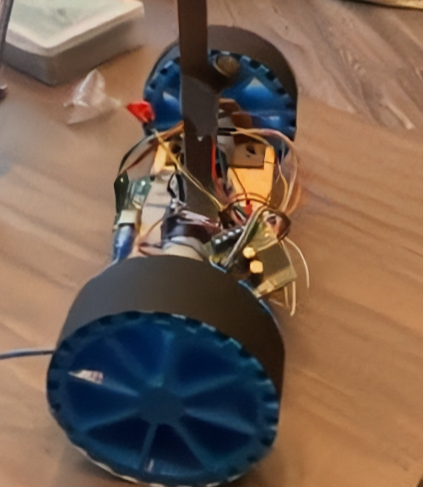
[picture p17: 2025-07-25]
self-balance/image.jpg

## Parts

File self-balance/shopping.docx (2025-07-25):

# Final Shopping List – Self-Balancing Robot Project

This document contains the finalized list of hardware components and accessories required to construct and operate the two-wheeled self-balancing robot. This includes motor and sensor hardware, power management, microcontroller components, mechanical structure, and wiring essentials.

# 1. Core Electronics

- ESP32 Microcontroller Board (DevKit v1 or similar)
- MPU6050 or MPU9250 IMU Sensor Module (Accelerometer + Gyroscope)
- L298N Dual H-Bridge Motor Driver
- 2x Pololu 3701 6V DC Gear Motors (31.25:1 gear ratio)
- 2x 5-inch Diameter Wheels (compatible with motor shafts)

# 2. Power Supply and Regulation

- 12V Li-ion or LiPo Battery Pack (2S or 3S, ≥2000mAh recommended)
- 2x Buck Converters (MP1584 or LM2596) – One for 5V (ESP32), one for 5V (L298N logic)
- SPST Toggle Switch – for battery cut-off to both buck converters
- Voltage display module (optional, to monitor battery status)

# 3. Wiring and Connectivity

- Male-to-Male and Male-to-Female Jumper Wires
- Silicone Insulated Power Wires (16–22 AWG)
- Screw Terminal Blocks or Soldering Kit
- Breadboard or Perfboard (optional for power distribution)
- Heat Shrink Tubing or Electrical Tape
- Zip Ties or Velcro Straps for Wire Management

# 4. Mechanical and Structural Components

- 3D Printed Chassis Components (base, motor mounts, electronics trays)
- Battery Holder or Tray
- Foam Tape or Rubber Mounts (for IMU vibration isolation)
- Screws, Nuts, and Washers for Motor and Frame Assembly
- IMU Mounting Bracket (centered at wheel axle level)

# 5. Optional Decorative Components

- 3D Printed Darth Vader Figurine (4-inch tall)
- Custom Enclosure or Themed Shell (optional aesthetic addition)

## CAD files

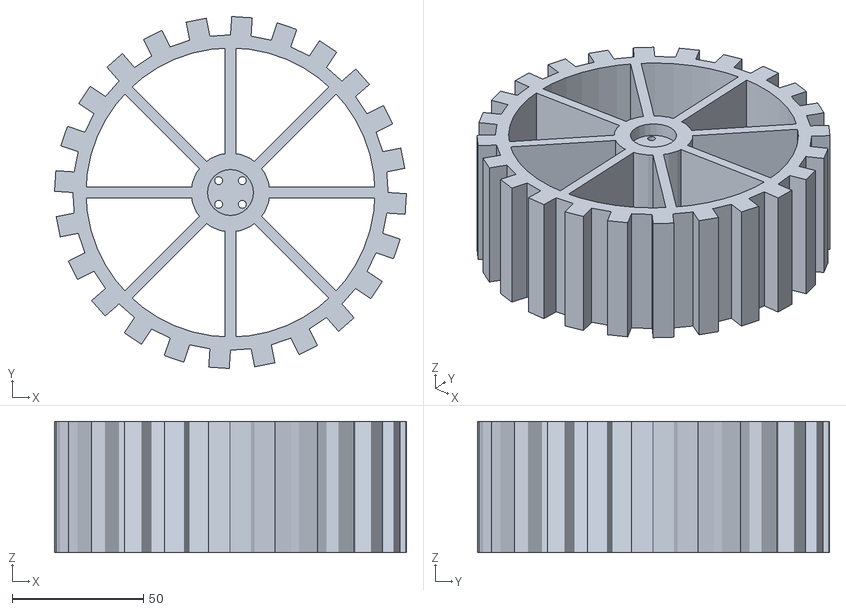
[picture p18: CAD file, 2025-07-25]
self-balance/wheel.stl
134.0 x 134.0 x 50.0
